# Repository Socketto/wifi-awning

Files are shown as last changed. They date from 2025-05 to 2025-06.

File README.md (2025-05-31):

# Project Overview: Wind Alarm Awning Control Replacement System

This project was developed to replace a faulty awning control board that is triggered in case of high wind conditions. The system uses an anemometer to detect wind speed, and through a control board equipped with an onboard trimmer, it allows the user to set a wind speed threshold. Once this threshold is exceeded, the awning is automatically retracted to prevent wind damage.

## Original Control Board: Firmware Bug

The original board, while functional in normal conditions, presents a critical firmware issue. Below is a step-by-step breakdown of the standard operation and the bug scenario:

### Normal Operation:
1. The awning is lowered via manual or remote control.
2. The board executes the command and lowers the awning.
3. If wind speed exceeds the set threshold, the board retracts the awning and leaves it retracted.

### Bug Scenario:
1. The awning is lowered using the control commands.
2. The board properly lowers the awning.
3. Upon high wind detection, the board retracts the awning as expected.
4. While outside the building, the user manually lowers the awning using the crank handle.
5. The board does not detect that the awning was manually lowered.
6. If wind conditions worsen again, the board fails to retract the awning, leaving it exposed to damage.

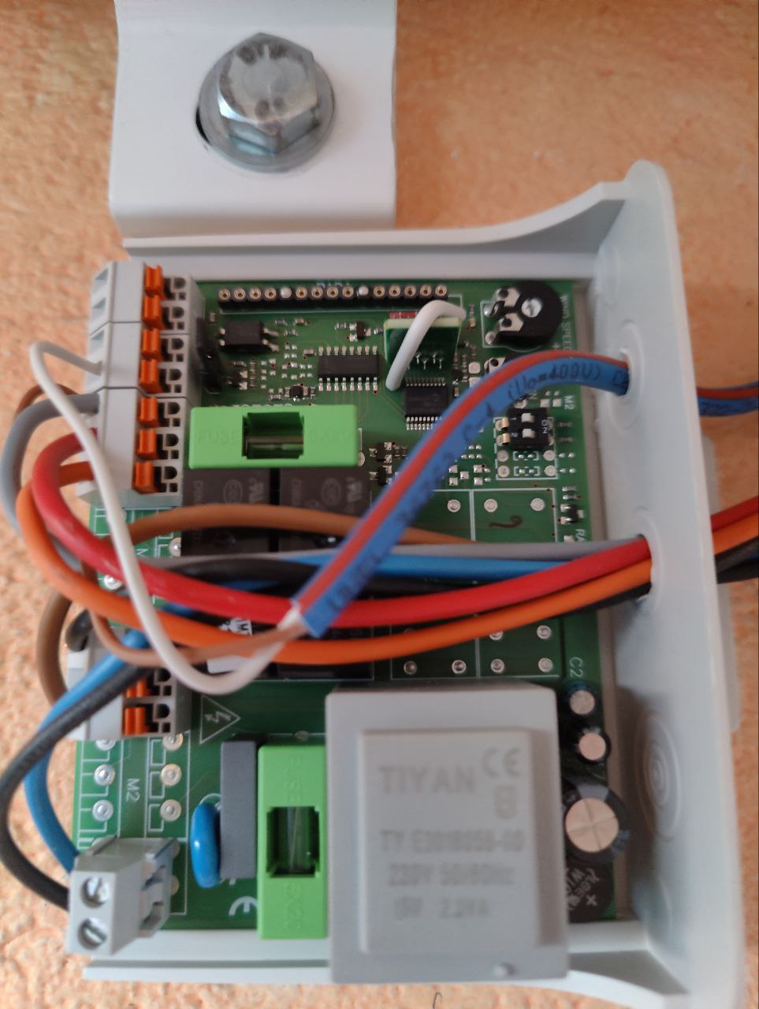
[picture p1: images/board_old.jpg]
Board


## New Control Board: Fully Programmable and Wi-Fi Enabled

The replacement board is fully programmable, supporting both Arduino and ESP-IDF environments. This flexibility allows for quick and permanent fixes to firmware bugs like the one described above. Additionally, the board natively supports Wi-Fi connectivity for remote monitoring and updates.

## Advanced Features:

- **Current Sensor Integration:**  
  A current sensor is integrated directly on the board and connected to an ADC1 pin. This feature enables the system to control the awning opening to a specific percentage. Once programmed with a calibration sequence, the system can learn and control precise positions.

- **Debug and Display Capabilities:**
  - **Serial Interface:** For real-time debugging and logging.
  - **RGB LED:** Programmable for visual status indicators.
  - **LCD Display Support:** Allows the connection of an LCD screen to show system status and operational feedback.
  
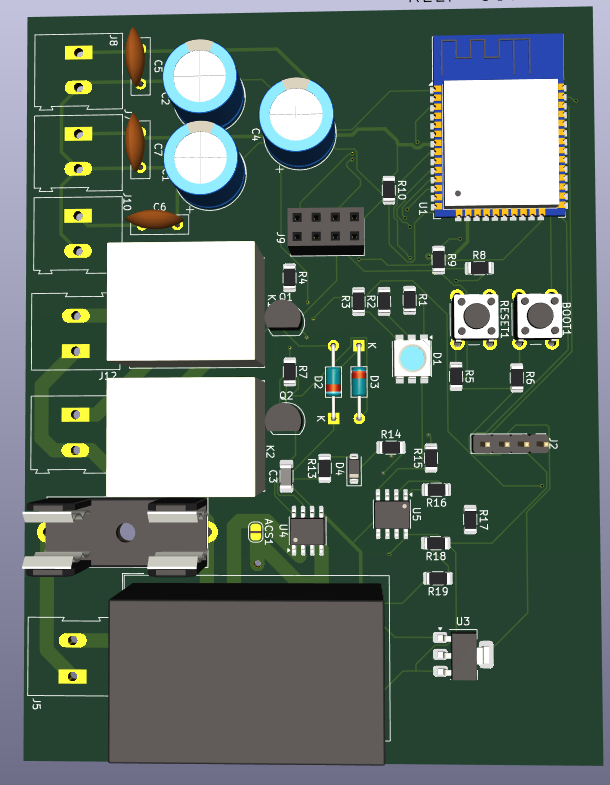
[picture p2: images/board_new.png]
Board


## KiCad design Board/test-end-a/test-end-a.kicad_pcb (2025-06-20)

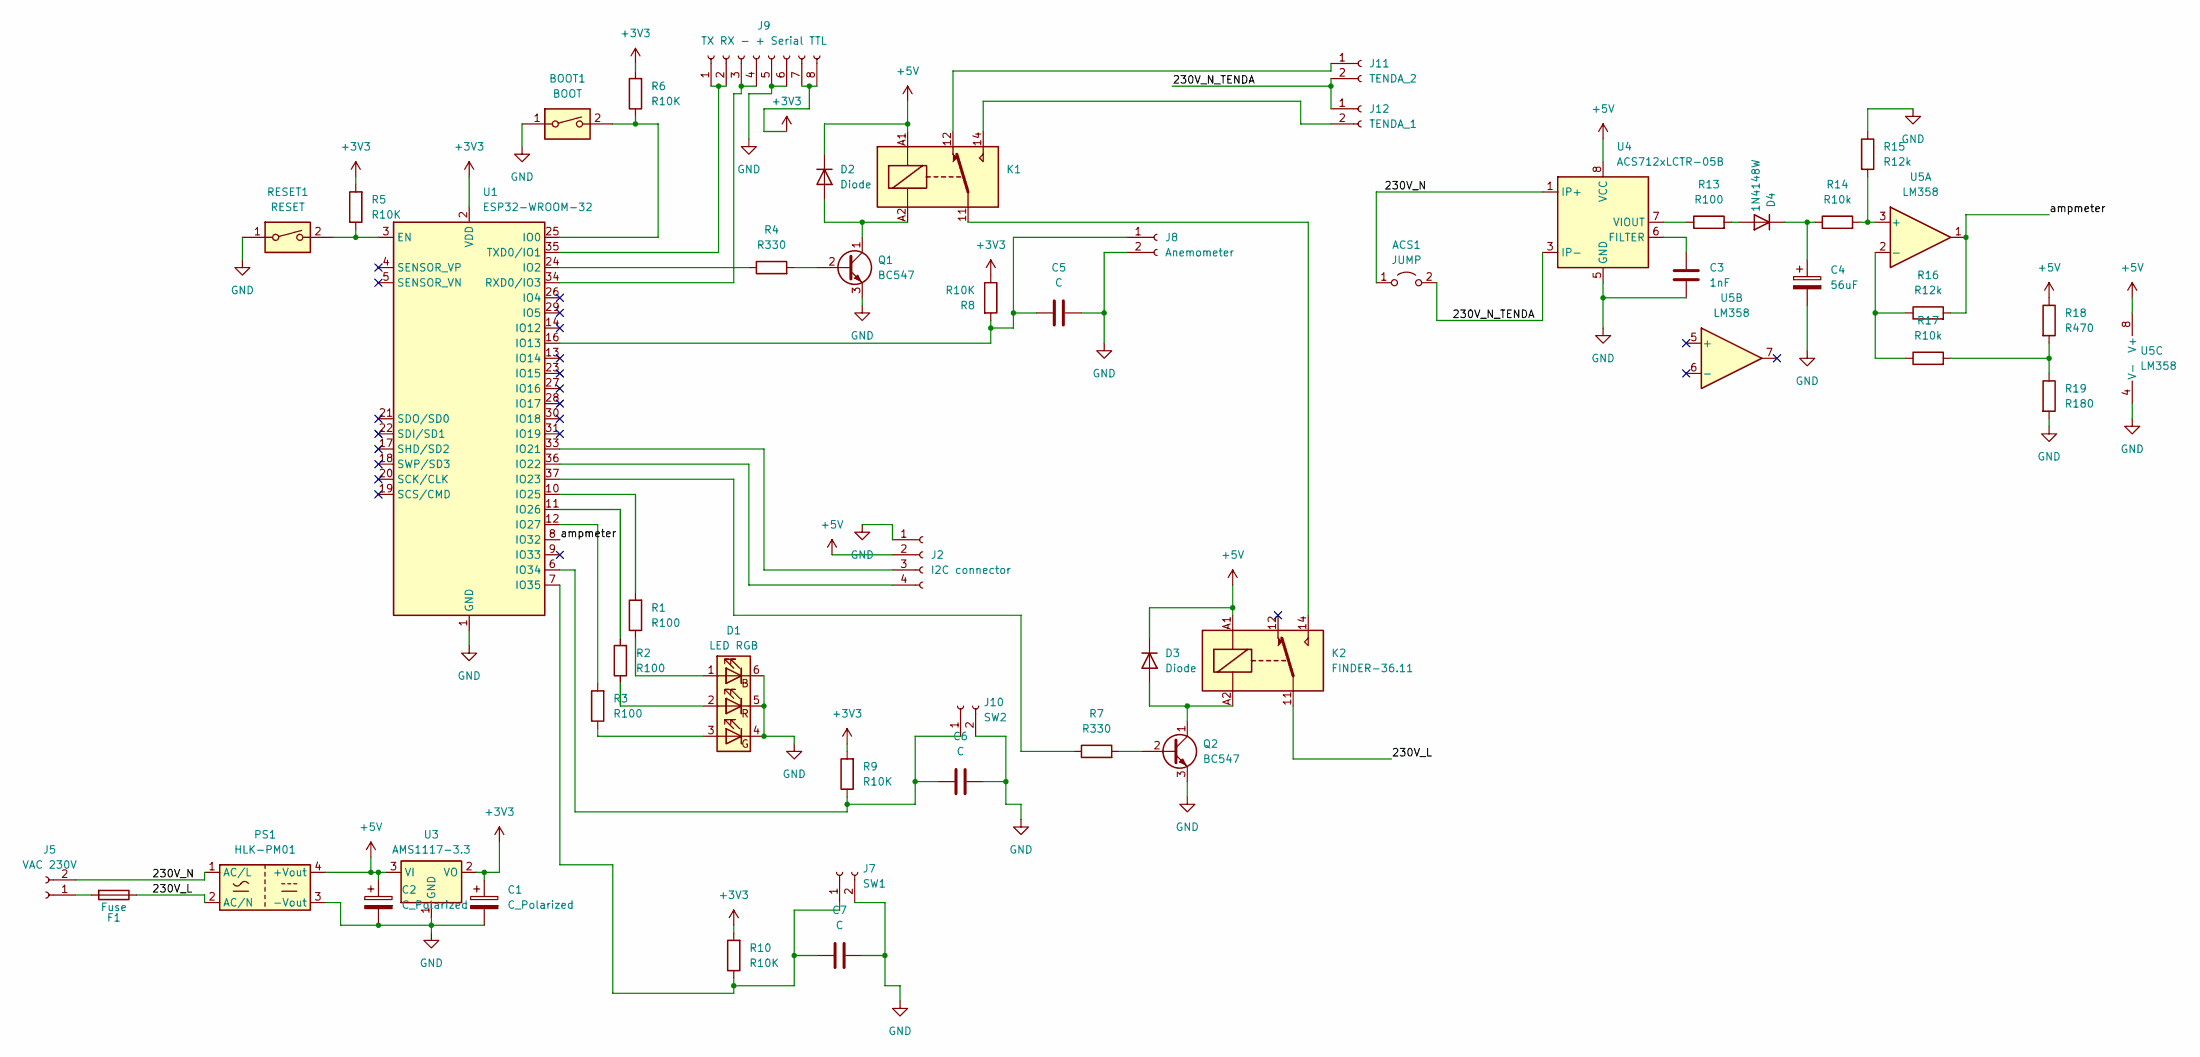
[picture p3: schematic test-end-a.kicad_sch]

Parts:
ACS1: JUMP; SolderJumper-2_P1.3mm_Open_RoundedPad1.0x1.5mm
BOOT1: BOOT; SW_PUSH_6mm_H4.3mm
C1, C2: C_Polarized; CP_Radial_D10.0mm_P5.00mm
C3: 1nF; L_1206_3216Metric_Pad1.22x1.90mm_HandSolder
C4: 56uF; CP_Radial_D10.0mm_P5.00mm
C5, C6, C7: C; C_Disc_D8.0mm_W2.5mm_P5.00mm
D1: LED RGB; LED_RGB_5050-6
D2, D3: Diode; D_DO-35_SOD27_P10.16mm_Horizontal
D4: 1N4148W; D_SOD-123
F1: Fuse; Fuseholder_Cylinder-5x20mm_Schurter_0031_8201_Horizontal_Op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
J2: I2C connector; PinHeader_1x04_P2.54mm_Vertical
J5: VAC 230V; TerminalBlock_Altech_AK300-2_P5.00mm
J7: SW1; TerminalBlock_Altech_AK300-2_P5.00mm
J8: Anemometer; TerminalBlock_Altech_AK300-2_P5.00mm
J9: TX RX - + Serial TTL; PinSocket_2x04_P2.54mm_Vertical
J10: SW2; TerminalBlock_Altech_AK300-2_P5.00mm
J11: TENDA_2; TerminalBlock_Altech_AK300-2_P5.00mm
J12: TENDA_1; TerminalBlock_Altech_AK300-2_P5.00mm
K1, K2: FINDER-36.11; Relay_SPDT_Finder_36.11
PS1: HLK-PM01; Converter_ACDC_Hi-Link_HLK-PMxx
Q1, Q2: BC547; TO-92_Inline
R1, R2, R3, R13: R100; R_1206_3216Metric
R4, R7: R330; R_1206_3216Metric
R5, R6, R8, R9, R10: R10K; R_1206_3216Metric
R14, R17: R10k; R_1206_3216Metric
R15, R16: R12k; R_1206_3216Metric
R18: R470; R_1206_3216Metric
R19: R180; R_1206_3216Metric
RESET1: RESET; SW_PUSH_6mm_H4.3mm
U1: ESP32-WROOM-32
U3: AMS1117-3.3; SOT-223-3_TabPin2
U4: ACS712xLCTR-05B; SOIC-8_3.9x4.9mm_P1.27mm
U5: LM358; SOIC-8-1EP_3.9x4.9mm_P1.27mm_EP2.29x3mm

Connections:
+3V3: C1.1, J9.7, J9.8, R5.2, R6.2, R8.1, R9.2, R10.2, U1.2 (VDD), U3.2 (VO)
+5V: C2.1, D2.1 (K), D3.1 (K), J2.2, K1.A1, K2.A1, PS1.4 (+Vout), R18.1, U3.3 (VI), U4.8 (VCC), U5.8 (V+)
/230V_L: F1.1, K2.11, PS1.2 (AC/N)
/230V_N: ACS1.1 (A), J5.2, PS1.1 (AC/L), U4.1 (IP+), U4.2 (IP+)
/230V_N_TENDA: ACS1.2 (B), J11.2, J12.1, U4.3 (IP-), U4.4 (IP-)
/ampmeter: R16.2, U1.8 (IO32), U5.1
GND: BOOT1.1, C1.2, C2.2, C3.2, C4.2, C5.2, C6.2, C7.2, D1.4 (GK), D1.5 (RK), D1.6 (BK), J2.1, J7.2, J8.2, J9.5, J9.6, J10.2, PS1.3 (-Vout), Q1.3 (E), Q2.3 (E), R15.1, R19.2, RESET1.1, U1.1 (GND), U1.15 (GND), U1.38 (GND), U1.39 (GND), U3.1 (GND), U4.5 (GND), U5.4 (V-)
unnamed: D1.1 (BA), R1.1
unnamed: D1.3 (GA), R3.1
unnamed: D1.2 (RA), R2.1
unnamed: D2.2 (A), K1.A2, Q1.1 (C)
unnamed: D3.2 (A), K2.A2, Q2.1 (C)
unnamed: D4.2 (A), R13.2
unnamed: C4.1, D4.1 (K), R14.1
unnamed: J2.3, U1.33 (IO21)
unnamed: J2.4, U1.36 (IO22)
unnamed: F1.2, J5.1
unnamed: C7.1, J7.1, R10.1, U1.7 (IO35)
unnamed: C5.1, J8.1, R8.2, U1.16 (IO13)
unnamed: J9.1, J9.2, U1.35 (TXD0/IO1)
unnamed: J9.3, J9.4, U1.34 (RXD0/IO3)
unnamed: C6.1, J10.1, R9.1, U1.6 (IO34)
unnamed: J11.1, K1.12
unnamed: J12.2, K1.14
unnamed: K1.11, K2.14
unnamed: Q1.2 (B), R4.2
unnamed: Q2.2 (B), R7.2
unnamed: R17.2, R18.2, R19.1
unnamed: R5.1, RESET1.2, U1.3 (EN)
unnamed: BOOT1.2, R6.1, U1.25 (IO0)
unnamed: R4.1, U1.24 (IO2)
unnamed: R7.1, U1.37 (IO23)
unnamed: R1.2, U1.10 (IO25)
unnamed: R2.2, U1.11 (IO26)
unnamed: R3.2, U1.12 (IO27)
unnamed: C3.1, U4.6 (FILTER)
unnamed: R13.1, U4.7 (VIOUT)
unnamed: R14.2, R15.2, U5.3 (+)
unnamed: R16.1, R17.1, U5.2 (-)

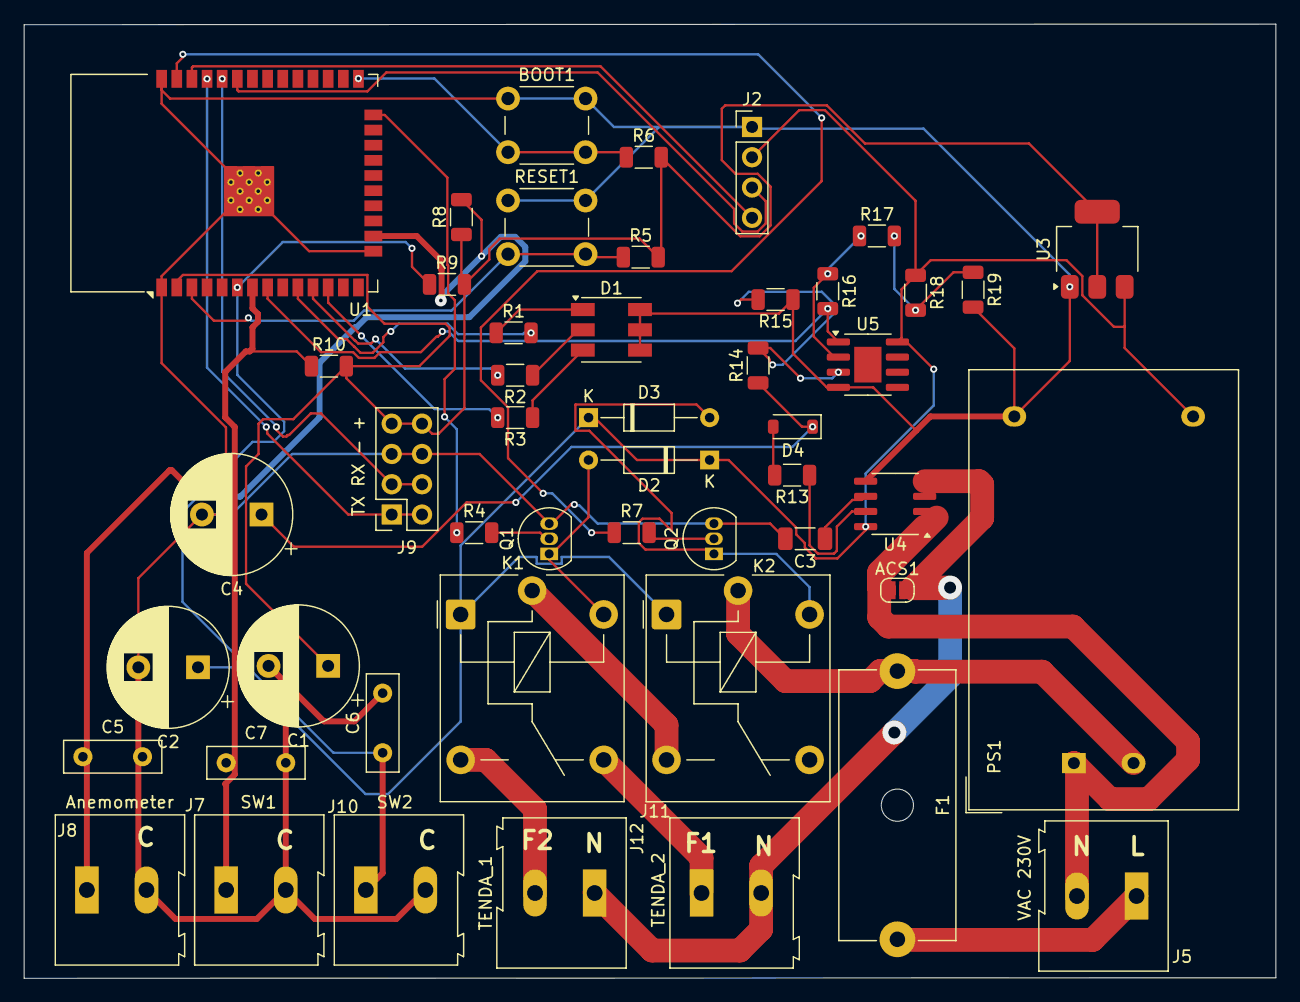
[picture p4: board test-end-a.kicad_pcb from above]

Board: 2 copper layers, 105.0 x 80.0 mm, 49 parts (0 on the bottom side), 39 nets.

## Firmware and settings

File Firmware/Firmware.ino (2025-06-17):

#include <Wire.h>
#include <LiquidCrystal_I2C.h>

LiquidCrystal_I2C lcd(0x27, 16, 2);

// Pin configuration
const int PIN_UP = 34;
const int PIN_DOWN = 35;
const int RELAY_POWER = 23;
const int RELAY_DIRECTION = 2;
const int ANEMO_PIN = 13;

const int GREEN_LED = 27;
const int RED_LED = 26;  //25

// Wind sensor parameters
volatile unsigned int tickCount = 256;
unsigned long lastWindCheck = 0;
const unsigned long WIND_CHECK_INTERVAL = 3000;
const int WIND_TICK_THRESHOLD = 5;

// Debounce
unsigned long lastDebounceTimeUP = 0;
unsigned long lastDebounceTimeDOWN = 0;
const unsigned long DEBOUNCE_DELAY = 50;
bool lastButtonStateUP = HIGH;
bool lastButtonStateDOWN = HIGH;
bool buttonStateUP = HIGH;
bool buttonStateDOWN = HIGH;

// State
bool windAlarmActive = false;
unsigned long alarmStartTime = 0;
bool raisingInProgress = false;
unsigned long raiseStartTime = 0;
unsigned short countergreen = 0;

const unsigned long ALARM_RESET_TIMEOUT = 60000 * 7;  //7 minutes
const unsigned long ALARM_STOP_UP_TIMEOUT = 60000;

// LED blink
unsigned long lastBlinkTime = 0;
bool ledState = false;
volatile unsigned long lastInterruptTime = 0;

void IRAM_ATTR windSensorISR() {
  unsigned long currentTime = millis();
  if (currentTime - lastInterruptTime > 10) {  // 10ms
    tickCount++;
    lastInterruptTime = currentTime;
  }
}

void setup() {
  Serial.begin(115200);

  pinMode(PIN_UP, INPUT_PULLUP);
  pinMode(PIN_DOWN, INPUT_PULLUP);
  pinMode(RELAY_POWER, OUTPUT);
  pinMode(RELAY_DIRECTION, OUTPUT);
  pinMode(ANEMO_PIN, INPUT_PULLUP);

  pinMode(GREEN_LED, OUTPUT);
  pinMode(RED_LED, OUTPUT);

  attachInterrupt(digitalPinToInterrupt(ANEMO_PIN), windSensorISR, FALLING);

  digitalWrite(RELAY_POWER, LOW);
  digitalWrite(RELAY_DIRECTION, LOW);

  lcd.init();
  lcd.backlight();
  lcd.setCursor(0, 0);
  lcd.print("Sistema pronto");
  delay(1000);
  lcd.clear();
}

void loop() {
  unsigned long currentMillis = millis();

  // --- LED blinking ---
  if (windAlarmActive) {
    if (currentMillis - lastBlinkTime >= 100) {
      ledState = !ledState;
      digitalWrite(RED_LED, ledState);
      if (raisingInProgress) {
        digitalWrite(GREEN_LED, LOW);
      } else {
        digitalWrite(GREEN_LED, ledState);
      }
      lastBlinkTime = currentMillis;
    }
  } else {
    if (currentMillis - lastBlinkTime >= 100) {
      countergreen++;
      ledState = countergreen % 50 == 0;
      digitalWrite(GREEN_LED, ledState);
      digitalWrite(RED_LED, LOW);
      lastBlinkTime = currentMillis;
    }
  }

  // --- Wind check ---
  if (currentMillis - lastWindCheck >= WIND_CHECK_INTERVAL) {
    lastWindCheck = currentMillis;

    Serial.print("Wind tick/s: ");
    Serial.println(tickCount);
    lcd.setCursor(0, 0);
    lcd.print("Wind tick:      ");
    lcd.setCursor(11, 0);
    lcd.print(tickCount);

    if (tickCount >= WIND_TICK_THRESHOLD && !windAlarmActive) {
      windAlarmActive = true;
      alarmStartTime = currentMillis;
      retractAwningDueToAlarm();
    }

    tickCount = 0;
  }

  // --- Wind alarm reset ---
  if (windAlarmActive) {
    lcd.setCursor(0, 1);
    lcd.print("Allarme!       ");
    lcd.setCursor(9, 1);
    lcd.print((ALARM_RESET_TIMEOUT/1000) - ((unsigned long)((currentMillis - alarmStartTime) / 1000)));
    if (currentMillis - alarmStartTime >= ALARM_RESET_TIMEOUT) {
      Serial.println("Wind alarm reset.");
      lcd.setCursor(0, 1);
      lcd.print("Allarm reset   ");
      raisingInProgress = false;
      windAlarmActive = false;
    } else {
      if (currentMillis - alarmStartTime >= ALARM_STOP_UP_TIMEOUT) {
        Serial.println("Wind alarm stop UP.");
        raisingInProgress = false;
      } else {
        raiseAwning();
      }
    }
  }

  // --- Button debounce logic ---
  bool readingUP = digitalRead(PIN_UP);
  if (readingUP != lastButtonStateUP) {
    lastDebounceTimeUP = currentMillis;
  }
  if ((currentMillis - lastDebounceTimeUP) > DEBOUNCE_DELAY) {
    if (readingUP != buttonStateUP) {
      buttonStateUP = readingUP;
      if (buttonStateUP == LOW && !windAlarmActive) {
        raiseAwning();
      }
    }
  }
  lastButtonStateUP = readingUP;

  bool readingDOWN = digitalRead(PIN_DOWN);
  if (readingDOWN != lastButtonStateDOWN) {
    lastDebounceTimeDOWN = currentMillis;
  }
  if ((currentMillis - lastDebounceTimeDOWN) > DEBOUNCE_DELAY) {
    if (readingDOWN != buttonStateDOWN) {
      buttonStateDOWN = readingDOWN;
      if (buttonStateDOWN == LOW && !windAlarmActive) {
        lowerAwning();
      }
    }
  }
  lastButtonStateDOWN = readingDOWN;

  // Stop motor if no button pressed and no automatic raise
  if (buttonStateUP == HIGH && buttonStateDOWN == HIGH && !raisingInProgress) {
    stopAwning();
  }
}

// --- Relay logic updated to support double-deviator wiring ---

void raiseAwning() {
  Serial.println("UP.");
  if (raisingInProgress == false) {
    lcd.setCursor(0, 1);
    lcd.print("Salita...       ");
  }
  digitalWrite(RELAY_DIRECTION, LOW);  // Direction: UP
  delay(100);                          // Small delay to settle relays
  digitalWrite(RELAY_POWER, HIGH);     // Power ON
}

void lowerAwning() {
  Serial.println("DOWN.");
  lcd.setCursor(0, 1);
  lcd.print("Discesa...      ");
  digitalWrite(RELAY_DIRECTION, HIGH);  // Direction: DOWN
  delay(100);
  digitalWrite(RELAY_POWER, HIGH);  // Power ON
}

void stopAwning() {
  digitalWrite(RELAY_POWER, LOW);  // Power OFF
  delay(100);
  digitalWrite(RELAY_DIRECTION, LOW);  // Direction: DOWN
  Serial.println("stopAwning");
  if (windAlarmActive == false) {
    lcd.setCursor(0, 1);
    lcd.print("Fermo           ");
  }
}

void retractAwningDueToAlarm() {
  Serial.println("Wind alarm! Retracting awning...");
  raisingInProgress = true;
  raiseStartTime = millis();
}

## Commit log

2025-05-31 [FIRST] First commit of awning
    [test-end-a.kicad_pcb, test-end-a.kicad_sch]
2025-05-31 [ADD] Add consumption scheme and components on the board
    [test-end-a.kicad_pcb, test-end-a.kicad_sch]
2025-05-31 [ENH] Move a wire to avoid interferences with high voltage
    [test-end-a.kicad_pcb]
2025-06-15 [UPD] Update firmware with board pinout
2025-06-16 [UPD] Update led color
2025-06-18 [FIX] Fix board dimensions
    [test-end-a.kicad_pcb, test-end-a.kicad_sch]
2025-06-20 [ADD] Add labels
    [test-end-a.kicad_pcb]
